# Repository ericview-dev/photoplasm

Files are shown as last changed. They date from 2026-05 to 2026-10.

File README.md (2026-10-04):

# Photoplasm

**Optogenetic bacteriography exposure unit — HTGAA 2026 Final Project**

*Eric Schneider · Makerspace Charlotte · BioArt Studio*

---

## What It Is

Photoplasm is a Raspberry Pi 5-based optogenetic exposure unit designed for bacteriographic imaging — using spatially-patterned 470 nm light to control gene expression in engineered bacteria. A 128×64 OLED acts as a programmable digital photomask, projecting custom grayscale patterns onto a bacterial culture plate through a 470 nm LED ring. An AS7341 spectral sensor measures delivered irradiance at the substrate plane in real time.

The result is a benchtop instrument capable of exposing a bacterial plate to a calibrated, spatially-defined light pattern — the optical equivalent of an enlarger in photographic darkroom practice, but for living cells.

---

## Hardware

| Component | Role |
|---|---|
| Raspberry Pi 5 | Host compute, GPIO, SPI, I²C, PWM |
| Waveshare SSD1309 128×64 OLED (SPI) | Digital photomask — spatial light modulator |
| 9× 470 nm LED ring | Primary illumination source |
| IRLZ44N MOSFET | PWM gate driver for LED ring (GPIO18) |
| Godiyes AS7341 spectral sensor (I²C) | 10-channel irradiance measurement at substrate |
| PTC heater + DS18B20 (1-Wire) | 37°C incubation thermal control |
| Raspberry Pi Camera Module | Sample imaging and machine vision (planned) |

Pin assignments: [`Docs/appendix_C_pinout_NS-03_v8.md`](Docs/appendix_C_pinout_NS-03_v8.md)

---

## Scripts

| Script | Purpose |
|---|---|
| [`Software/photoplasm_densitometer.py`](Software/photoplasm_densitometer.py) | 16-step Bayer dither transmission densitometer — characterises OLED optical neutrality at 470 nm |
| [`Software/photoplasm_cal01.py`](Software/photoplasm_cal01.py) | 16-step sensitometric calibration sweep using cumulative pie-wedge masks (Stouffer step wedge equivalent) |
| [`Software/photoplasm_cal02.py`](Software/photoplasm_cal02.py) | Three-state irradiance calibration (display off / display on / all-white) |

### Quick start — densitometer

```bash
# Install dependencies
sudo apt install python3-lgpio python3-spidev python3-smbus2 python3-pil
sudo pip3 install adafruit-circuitpython-as7341 --break-system-packages

# Run (requires hardware)
sudo python3 Software/photoplasm_densitometer.py

# Dry run — no hardware required
python3 Software/photoplasm_densitometer.py --dry-run

# Options
sudo python3 Software/photoplasm_densitometer.py --gain 128X --settle 2.0 --pwm 80
```

Output: timestamped CSV in `cal_logs/` with per-step spectral channel readings and regression summary printed to stdout.

---

## Documentation

Full build and operation guide in [`Docs/`](Docs/):

| # | Chapter | Status |
|---|---|---|
| 1 | [SSH Setup & VS Code Remote Development](Docs/photoplasm_ch01_ssh.md) | published |
| 2 | [GitHub & Version Control](Docs/photoplasm_ch02_github.md) | published |
| 3 | [Wavelength Sensor — AS7341](Docs/photoplasm_ch03_wavelength_sensor.md) | draft |
| 4 | [LED Ring · 470nm PWM Control](Docs/photoplasm_ch04_led_ring.md) | published |
| 5 | [OLED Digital Image Mask](Docs/photoplasm_ch05_oled_mask.md) | draft |
| 6 | [Incubation Heater Perfboard](Docs/photoplasm_ch06_heater_perfboard.md) | published |
| 7 | [System Integration](Docs/photoplasm_ch07_system_integration.md) | draft |
| 8 | [GUI / Flask Web Interface](Docs/photoplasm_ch08_gui_flask.md) | draft |
| 9 | [SpacePlacer — Perfboard Layout Tool](Docs/photoplasm_ch09_spaceplacer.md) | draft |
| 10 | [Camera Module](Docs/photoplasm_ch10_camera_module.md) | placeholder |
| A | [Calibration Protocol](Docs/appendix_A_calibration_protocol.md) | draft |
| B | [Feature Specification](Docs/appendix_B_feature_specification.md) | working draft |
| C | [Pinout — NS-03 v8](Docs/appendix_C_pinout_NS-03_v8.md) | working draft |

---

## Project Status

Active development on the `dev` branch. Hardware subsystems operational: LED ring, OLED mask, AS7341 sensor, incubation heater. Calibration scripts validated. Flask GUI and camera module in scope.

---

## License

Photoplasm follows a Pioreactor-style open-source model: different parts of the project
carry the license that suits what each part is.

| | | |
|---|---|---|
| `Software/` | **MIT** | permissive reuse, attribution required |
| `Docs/` · `Guide/` | **CC BY-SA 4.0** | share and adapt, including commercially, under the same license |
| `3D/` | **CERN-OHL-S-2.0** | strongly reciprocal hardware licence |

Source code is MIT wherever it sits — placement does not change a file's license, its
nature does. The Photoplasm name, branding, unpublished know-how and separately protected
inventions are reserved and fall outside all three.

Full terms, including third-party materials: [`LICENSE`](LICENSE)

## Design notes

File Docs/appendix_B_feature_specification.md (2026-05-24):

Photoplasm Quick Start Guide  ·  Appendix B: Feature Specification **Photoplasm**

**Appendix B: Feature Specification**

**Version: **v0.18 (working draft)

**Status: **Working functional specification — locks at release milestone **Date: **2026-05-17 **Repository: **github.com/ericview-dev/photoplasm **Author: **Eric Schneider

# About This Document

This appendix is the functional specification for Photoplasm, the Raspberry Pi-based optogenetic exposure unit at the heart of the BioLight project. It catalogs every feature of the device — hardware subsystems, software components, mechanical assemblies, and platform infrastructure — and tracks each feature's design intent, implementation status, and supporting build assets.

The specification is organized as a registry rather than a narrative. Each feature has a permanent identifier (such as LED-01 or CAM-01.2), a category grouping, and a row in the registry table. Detailed specifications for each feature follow the registry in the appendix body. The registry serves as the index; the body provides the depth.

## Working Document, Locked at Release

This is a working functional specification. It evolves as features are designed, scoped, built, and tested. Entries are added, statuses change, sub-features are decomposed, and upgrade paths emerge throughout development. Internal revision history is tracked at the end of this appendix; it captures the document's own evolution and is intended for working reference, not publication.

When Photoplasm reaches a release milestone, the specification is locked: statuses are reconciled, the working revision history is archived, and a final published version is produced. Until then, the specification is a living document, and the registry reflects the current state of the project rather than any single committed plan.

# Legend

## Category Codes

| **Code** | **Category** | **Scope** |
| --- | --- | --- |
| **SYS** | System & Lifecycle | Boot, shutdown, services, power management, platform-level concerns |
| **GUI** | Operator Interface | Flask web UI, kiosk panel, CLI, all user-facing controls |
| **LED** | Light Generation (EBOOT-based) | Current prototype: 9× 470 nm through-hole LEDs |
| **CRE** | Light Generation (Cree XP-E2) | Upgrade lightring: high-output star LEDs with heatsink, diffuser, fan |
| **MSK** | Image Mask | Variable-density image layer between light and sample |
| **WAV** | Spectral Measurement | Wavelength-based sensing of the light source; calibration, characteristic curves |
| **HTR** | Thermal Subsystem | Heater element, MOSFET driver, temperature sensing, control loop |
| **OPT** | Optical Isolation | Dark chamber, frustum, baffles, sample stage, passive optics |
| **CAM** | Imaging & Machine Vision | Camera-based observation of the sample; image acquisition, analysis pipelines |

## Status Lifecycle

| **Status** | **Meaning** |
| --- | --- |
| **🔵 Proposed** | Identified, rationale captured, not yet scoped |
| **🟡 Scoped** | Implementation path defined, parts listed, awaiting build |
| **🟢 In Progress** | Active development; hardware wiring, code, or both underway |
| **🧪 Tested** | Built and bench-verified; awaiting integration into chapter spec |
| **✅ Complete** | Fully specified, built, tested, operational |
| **🗄️ Deferred** | Was active; now paused, superseded, or migrated to another category |
| **⛔ Rejected** | Considered and declined; rationale preserved |

## Upgrade Path Notation

Succession: → FEATURE-ID (superseded) or → FEATURE-ID.x (gains a sub-variant).

Gating: Gates FEATURE-ID — milestone dependency. A feature in the gating role typically defines a pass/fail criterion in its Brief Description.

# Feature Specification Registry

## 1. SYS — System & Lifecycle

| **ID** | **Title** | **Brief Description** | **Ch.** | **Status** | **Asset** | **Upgrade** |
| --- | --- | --- | --- | --- | --- | --- |
| **SYS-01** | Shutdown Button | GPIO21 momentary pull-up, graceful shutdown trigger | Ch. 7 | ✅ Complete | ✅ sys_01_shutdown.py | → SYS-03.2 |
| **SYS-02** | System Endpoints | /api/system/{shutdown,reboot,status} + signal handlers | Ch. 8 | 🟡 Scoped | 📝 sys_02_endpoints.py | → SYS-03 |
| **SYS-03** | Power Module | On/off/reboot module: hard switch, soft buttons, wake control | Ch. 8 | 🔵 Proposed | 📝 sys_03_power.py | — |
| **SYS-03.1** | Hard Power Switch | SPST rocker, 5V interrupt | Ch. 8 | 🔵 Proposed | ⬜ N/A | — |
| **SYS-03.2** | Soft Shutdown Button | Momentary, GPIO-triggered graceful shutdown (replaces SYS-01) | Ch. 8 | 🔵 Proposed | 📝 sys_03_2_soft_shutdown.py | — |
| **SYS-03.3** | Wake Button | Momentary on Pi 5 PWR_BTN header for wake-from-shutdown | Ch. 8 | 🔵 Proposed | ⬜ N/A | — |
| **SYS-03.4** | Reboot Control | Separate button or long-press gesture for reboot vs shutdown | Ch. 8 | 🔵 Proposed | 📝 sys_03_4_reboot.py | — |
| **SYS-04** | Battery Backup / UPS | Li-ion UPS HAT for graceful shutdown on power loss | Ch. 8 | 🔵 Proposed | 📝 sys_04_ups.py | — |
| **SYS-05** | Status LED Indicators | Front-panel LED stack | Ch. 8 | 🔵 Proposed | 📝 sys_05_status_leds.py | — |
| **SYS-05.1** | Pi Powered LED | Tied to 3V3 rail, lights when Pi has power | Ch. 8 | 🔵 Proposed | ⬜ N/A | — |
| **SYS-05.2** | System Ready LED | GPIO-driven, lights when Flask /health returns 200 | Ch. 8 | 🔵 Proposed | 📝 sys_05_2_ready_led.py | — |
| **SYS-05.3** | Shutdown In Progress LED | Blinks during graceful shutdown sequence | Ch. 8 | 🔵 Proposed | 📝 sys_05_3_shutdown_led.py | — |
| **SYS-06** | Battery-Backed RTC | Pi 5 onboard RTC with CR2032 cell for timestamp persistence | Ch. 8 | 🔵 Proposed | ⬜ N/A | — |
| **SYS-07** | Audible Status Cues | Piezo buzzer for shutdown, exposure complete, error states | Ch. 8 | 🔵 Proposed | 📝 sys_07_buzzer.py | — |
| **SYS-08** | Logging Infrastructure | Timestamped CSV writer shared across calibration + Flask | App. A / Ch. 7 | ✅ Complete | 🚧 sys_08_logger.py | — |
| **SYS-09** | lgpio Handle Pool | Shared GPIO claim/release management | Ch. 7 | ✅ Complete | 🚧 sys_09_gpio_pool.py | — |
| **SYS-10** | systemd Service Definition | Flask service unit for boot-time start | Ch. 8 | 🟡 Scoped | 📝 sys_10_photoplasm.service | Gates GUI-01, GUI-02 |
| **SYS-11** | Headless Pi 5 Configuration | OS install, hostname eyepi, user ericview, SSH, GPIO permissions | Ch. 7 | ✅ Complete | ⬜ N/A | — |
| **SYS-12** | Repo Sync Workflow | Three-way Mac ↔ GitHub ↔ Pi sync with HTTPS auth | Ch. 7 | ✅ Complete | ⬜ N/A | — |

## 2. GUI — Operator Interface

| **ID** | **Title** | **Brief Description** | **Ch.** | **Status** | **Asset** | **Upgrade** |
| --- | --- | --- | --- | --- | --- | --- |
| **GUI-01** | Flask UI — Mode 1 (Browser) | Browser-based control at http://eyepi.local:5000, systemd-managed | Ch. 8 | 🟡 Scoped | 📝 gui_01_browser.py | — |
| **GUI-02** | Flask UI — Mode 2 (Kiosk) | Chromium kiosk on Micro HDMI touchscreen, shares Mode 1 codebase | Ch. 8 | 🟡 Scoped | 📝 gui_02_kiosk.py | — |
| **GUI-02.1** | Chromium Launch Script | Kiosk-mode browser invocation with localhost target | Ch. 8 | 🟡 Scoped | 📝 gui_02_1_chromium_launch.sh | — |
| **GUI-02.2** | Touchscreen Hardware | 5-7" capacitive HDMI/DSI panel (specific model TBD) | Ch. 8 | 🔵 Proposed | ⬜ N/A | — |
| **GUI-03** | Click CLI Layer | flask photoplasm <subcommand> — unified CLI/web control path | Ch. 8 | 🟡 Scoped | 📝 gui_03_cli.py | — |
| **GUI-04** | Exposure Scheduling | Scheduled runs with duration, intensity, mask, incubation params | Ch. 8 | 🟡 Scoped | 📝 gui_04_scheduler.py | — |
| **GUI-05** | Mask Upload & Library | PNG/SVG upload to mask buffer with re-usable mask library | Ch. 8 | 🟡 Scoped | 📝 gui_05_mask_library.py | — |
| **GUI-06** | Live Sensor Dashboard | Real-time AS7341 + DS18B20 stream via SSE/WebSocket | Ch. 8 | 🟡 Scoped | 📝 gui_06_dashboard.py | — |
| **GUI-07** | Session Logging UI | Per-session timestamped CSV, downloadable from UI | Ch. 8 | 🟡 Scoped | 📝 gui_07_session_log.py | — |
| **GUI-08** | Touch-First UI Conventions | ≥64 px tap targets, bold typography, single stylesheet | Ch. 8 | 🟡 Scoped | 📝 gui_08_styles.css | — |
| **GUI-09** | Safelight-Aware Color Palette | Cool-tone primary chrome, red reserved for safelight-invisible states | Ch. 8 | 🟡 Scoped | 📝 gui_09_colors.css | — |
| **GUI-10** | Error State Handling | UI surfaces for hardware fault, sensor disconnect, mid-exposure failures | Ch. 8 | 🟡 Scoped | 📝 gui_10_errors.py | — |
| **GUI-11** | Multi-Client Concurrency | SSE/WebSocket fan-out for simultaneous browser + kiosk sessions | Ch. 8 | 🟡 Scoped | 📝 gui_11_realtime.py | — |

## 3. LED — Light Generation (EBOOT-based Lightring)

| **ID** | **Title** | **Brief Description** | **Ch.** | **Status** | **Asset** | **Upgrade** |
| --- | --- | --- | --- | --- | --- | --- |
| **LED-01** | LED Subsystem (Parent, EBOOT-based) | Variable-intensity 470 nm lightring; current prototype implementation | Ch. 4 | ✅ Complete | ✅ led_01_driver.py | → CRE-01 |
| **LED-01.1** | Breadboard/Protoboard Breakout | 9× 470 nm EBOOT LEDs, 3 strings of 3 series, 3×120Ω, 30-row protoboard | Ch. 4 | ✅ Complete | ✅ Present | → CRE-01 |
| **LED-01.2** | LED Matrix Board (alpha_01) | 120×120×2mm PETG, 9×9 diagonal RGB interleave, designed not built | Ch. 4 | 🟡 Scoped | 🚧 led_3D_01_2_matrix | → CRE-02 |
| **LED-01.3** | IRLZ44N PWM Gate Circuit | IRLZ44N at I15/I16/I17, 10kΩ G17-F20→GND, 3.3V gate at H17 | Ch. 4 | ✅ Complete | ✅ Present | — |
| **LED-03** | PWM Frequency Selection | LED PWM frequency (kHz) vs heater PWM (1-10 Hz) calibration | Ch. 4/7 | ✅ Complete | ✅ in led_01_driver.py | — |
| **LED-04** | Irradiance Measurement (EBOOT) | ~2.0 µW/cm² at 445nm; ~50× below 100 µW/cm² uncalibrated threshold² for blue-light optogenetic activation. Insufficient for eLightOn; drives CRE upgrade | Ch. 3 | ✅ Complete | ⬜ N/A | — |

## 4. CRE — Light Generation (Cree XP-E2 Lightring) — Priority 2 Upgrade

| **ID** | **Title** | **Brief Description** | **Ch.** | **Status** | **Asset** | **Upgrade** |
| --- | --- | --- | --- | --- | --- | --- |
| **CRE-01** | Cree Lightring Subsystem (Parent) | High-output Cree XP-E2 3-up star LED lightring; supersedes LED-01 at full integration | Ch. 4 | 🟡 Scoped (P2) | 📝 cre_01_driver.py | — |
| **CRE-01.1** | XP-E2 3-Up Star LEDs | 3× Cree XP-E2 3-up star modules (9 emitters total at 470 nm) — ordered | Ch. 4 | 🟡 Scoped (P2) | ⬜ N/A | — |
| **CRE-01.2** | 6.8Ω 2W Current-Limiting Resistors | Drive current resistors at 12V rail for rated XP-E2 forward current | Ch. 4 | 🟡 Scoped (P2) | ⬜ N/A | — |
| **CRE-01.3** | Passive Heatsink | Thermal management for star LED substrate, continuous-duty sized | Ch. 4 | 🔵 Proposed (P2) | 📝 cre_3D_01_3_heatsink | — |
| **CRE-01.4** | Active Cooling Fan | Forced airflow over heatsink for sustained high-drive operation | Ch. 4 | 🔵 Proposed (P2) | 📝 cre_01_4_fan.py | — |
| **CRE-01.5** | Light Diffuser | Optical diffuser to spread point-source emission for uniform exposure plane | Ch. 4/6 | 🔵 Proposed (P2) | 📝 cre_3D_01_5_diffuser | — |
| **CRE-02** | CRE Lightring Protoboard Design¹ | New SpacePlacer JSON sidecar; produced by existing SpacePlacer tool, no tool changes required | Ch. 4 | 🔵 Proposed (P2) | 📝 cre_lightring_alpha_01.json | — |
| **CRE-02.1** | CRE Layout JSON Artifact | cre_lightring_alpha_01.json — versioned design file in spaceplacer repo | Ch. 4 | 🔵 Proposed (P2) | 📝 cre_lightring_alpha_01.json | — |
| **CRE-02.2** | Heatsink Mounting Cutouts | Layout features for thermal contact between star LED substrate and heatsink | Ch. 4 | 🔵 Proposed (P2) | 📝 cre_3D_02_2_cutouts | — |
| **CRE-02.3** | Fan Mounting Provisions | Mechanical and electrical layout provisions for active cooling fan | Ch. 4 | 🔵 Proposed (P2) | 📝 cre_3D_02_3_fan_mount | — |
| **CRE-03** | CRE PWM Driver Adaptation | IRLZ44N driver verification at XP-E2 drive current; may require different gate scheme | Ch. 4 | 🔵 Proposed (P2) | 📝 in cre_01_driver.py | Gates CRE-01 |
| **CRE-04** | CRE Irradiance Measurement (Migration Gate) | AS7341 calibration of CRE at 470nm. Pass if ≥100 µW/cm²² (uncalibrated threshold). Fail if <100 µW/cm² (returns to engineering revision) | App. A | 🔵 Proposed (P2) | 📝 cre_04_irradiance.py | Gates CRE-06 |
| **CRE-05** | CRE Integration with Frustum Optics | Mounting and alignment of CRE assembly to existing OPT-01 dark chamber | Ch. 6 | 🔵 Proposed (P2) | 📝 cre_3D_05_frustum_adapter | — |
| **CRE-06** | CRE Migration & Cutover Plan | Procedure for swapping LED-01 → CRE-01 in operational unit | Ch. 4/7 | 🔵 Proposed (P2) | ⬜ N/A | — |

## 5. MSK — Image Mask

| **ID** | **Title** | **Brief Description** | **Ch.** | **Status** | **Asset** | **Upgrade** |
| --- | --- | --- | --- | --- | --- | --- |
| **MSK-01** | Image Mask Subsystem (Parent) | Variable-density image layer between LightRing and sample | Ch. 4/7 | ✅ Complete | ✅ msk_01_mask.py | — |
| **MSK-01.1** | OLED Implementation (SSD1309) | SPI transmissive mask — currently active, has 470 nm self-emission limitation | Ch. 4/7 | ✅ Complete | ✅ msk_01_1_oled.py | → MSK-01.2 |
| **MSK-01.2** | LCD Implementation (ILI9341) | Transmissive LCD backlit by LED array; eliminates self-emission | Ch. 4 | 🔵 Proposed | 📝 msk_01_2_lcd.py | — |
| **MSK-01.3** | Mask Mounting Hardware | Physical mount between LED rail and image mask layer | Ch. 6 | ✅ Complete | 🚧 msk_3D_01_3_mount | — |
| **MSK-02** | Bayer Dither Mask Generation | 16-step density gradient mask generation for densitometer sweeps | App. A | ✅ Complete | ✅ in wav_03_densitometer.py | — |

## 6. WAV — Spectral Measurement & Calibration

| **ID** | **Title** | **Brief Description** | **Ch.** | **Status** | **Asset** | **Upgrade** |
| --- | --- | --- | --- | --- | --- | --- |
| **WAV-01** | AS7341 Sensor | 10-channel I²C sensor at 0x39, drives calibration pipeline | Ch. 3 | ✅ Complete | ✅ wav_01_as7341.py | — |
| **WAV-01.1** | F1-F8 Spectral Channel Mapping | 415/445/480/515/555/590/630/680 nm channel definitions | Ch. 3 | ✅ Complete | ✅ in wav_01_as7341.py | — |
| **WAV-02** | Calibration Pipeline (Current) | Three-state irradiance, λex proxy, CSV logging | App. A | ✅ Complete | ✅ wav_02_calibration.py | — |
| **WAV-02.1** | Three-State Irradiance Method | Off / OLED-only / full exposure measurement methodology | App. A | ✅ Complete | ✅ in wav_02_calibration.py | — |
| **WAV-02.2** | λex Excitation Proxy | F2₄₄₅ + F3₄₈₀ summed-channel proxy for 470 nm excitation | App. A | ✅ Complete | ✅ in wav_02_calibration.py | — |
| **WAV-03** | Densitometer / H&D Sweep | 16-step Bayer dither, characteristic curves | App. A | ✅ Complete | ✅ wav_03_densitometer.py | — |
| **WAV-04** | (migrated to CAM-01) | Pi Camera Module — was tracked here under WAV when imaging was treated as a spectral concern; migrated to CAM category v0.14 | — | 🗄️ Deferred | — | → CAM-01 |
| **WAV-05** | Kc Coefficient Integration | Holds the irradiance coefficient (Kc) used to convert AS7341 raw counts to absolute µW/cm². Value derived externally through BioLight calibration protocol; Photoplasm consumes as configuration parameter | App. A | 🔵 Proposed | 📝 wav_05_kc_integration.py | — |
| **WAV-06** | Luminosity Reference (Clear Channel) | AS7341 clear channel for total flux measurement | App. A | ✅ Complete | ✅ in wav_02_calibration.py | — |

## 7. HTR — Thermal Subsystem

| **ID** | **Title** | **Brief Description** | **Ch.** | **Status** | **Asset** | **Upgrade** |
| --- | --- | --- | --- | --- | --- | --- |
| **HTR-01** | DS18B20 Temperature Sensor | 1-Wire sensor on GPIO4 (Pin 7), feeds heater control loop | Ch. 4/7 | ✅ Complete | ✅ htr_01_ds18b20.py | — |
| **HTR-01.1** | DS18B20 JST Wiring | T7=Data(orange/yellow), T8=GND(gray/black), T9=VDD(blue/red) | Ch. 4 | ✅ Complete | ⬜ N/A | — |
| **HTR-02** | PTC Element & Driver (Board B) | PTC via IRLZ44N on GPIO13/PWM1, closed loop with DS18B20 feedback | Ch. 4/7 | 🟡 Scoped | 📝 htr_02_controller.py | — |
| **HTR-02.1** | PTC Heating Element | Self-regulating positive-temperature-coefficient element | Ch. 4 | 🟡 Scoped | ⬜ N/A | — |
| **HTR-02.2** | IRLZ44N MOSFET Driver | Gate-driven from GPIO13/PWM1, switches 12V to PTC | Ch. 4 | 🟡 Scoped | ⬜ N/A | — |
| **HTR-02.3** | Heater PTC JST Connector | T4=PTC+, T5=PTC- | Ch. 4 | 🟡 Scoped | ⬜ N/A | — |
| **HTR-02.4** | Heater Board Layout (SpacePlacer) | Perfboard layout designed in github.com/ericview-dev/spaceplacer | Ch. 4 | 🟡 Scoped | 🚧 Board B JSON (spaceplacer) | — |
| **HTR-03** | PWM Bench Test Sequence | Independent verification of GPIO13/PWM1 before integration | Ch. 7 | 🟡 Scoped | 📝 htr_03_pwm_test.py | Gates HTR-02 |
| **HTR-04** | PID Control Loop | Temperature setpoint hold for 37 °C incubation | Ch. 8 | 🔵 Proposed | 📝 htr_04_pid.py | — |
| **HTR-05** | Heater Board Chamber | Physical enclosure subsection for Board B | Ch. 6 | 🔵 Proposed | 📝 htr_3D_05_chamber | — |

## 8. OPT — Optical Isolation

| **ID** | **Title** | **Brief Description** | **Ch.** | **Status** | **Asset** | **Upgrade** |
| --- | --- | --- | --- | --- | --- | --- |
| **OPT-01** | Dark Chamber — Frustum & Spacer Rings | Fixed cone (256mm × 51mm top × 152mm base) + stackable PETG spacers | Ch. 6 | ✅ Complete | ⬜ N/A | — |
| **OPT-01.1** | Frustum Cone | 256 mm height, 51 mm top ID, 152 mm base OD, PETG | Ch. 6 | ✅ Complete | 🚧 opt_3D_01_1_frustum | — |
| **OPT-01.2** | Spacer Ring (50 mm) | Stackable spacer for 6"-12" throw distance adjustment | Ch. 6 | ✅ Complete | 🚧 opt_3D_01_2_spacer | — |
| **OPT-02** | Modular Stacking Enclosure | PETG enclosure housing Pi, LED, mask, AS7341 | Ch. 6 | 🟢 In Progress | 🚧 opt_3D_02_enclosure | — |
| **OPT-03** | Sample Stage | Plate-holding stage at base of frustum (84 mm agar plate target) | Ch. 6 | ✅ Complete | 🚧 opt_3D_03_sample_stage | — |
| **OPT-04** | Light-Tight Sealing | Gaskets and overlap between stacked modules to prevent ambient leak | Ch. 6 | 🟡 Scoped | 📝 opt_3D_04_seals | — |

## 9. CAM — Imaging & Machine Vision

| **ID** | **Title** | **Brief Description** | **Ch.** | **Status** | **Asset** | **Upgrade** |
| --- | --- | --- | --- | --- | --- | --- |
| **CAM-01** | Pi Camera Module (Machine Vision) | RPi Camera Module for post-exposure sample imaging and fluorescence quantification | Ch. 10 | 🔵 Proposed | 📝 cam_01_capture.py | — |
| **CAM-01.1** | Camera Mount (Oblique or Under-Plate) | Physical mounting for fluorescence imaging at base of frustum | Ch. 6 | 🔵 Proposed | 📝 cam_3D_01_1_mount | — |
| **CAM-01.2** | Fluorescence Analytics Pipeline | Python image-analysis for sfGFP quantification | Ch. 10 | 🔵 Proposed | 📝 cam_01_2_fluorescence.py | — |

# Registry Footnotes

*Footnote markers are spaced superscript numerals following the relevant text (e.g., **"**µW/cm² ²**"**). The unspaced **"**²**"** in I²C elsewhere in the registry is the standard typographic rendering of the Inter-Integrated Circuit protocol name and is not a footnote reference.*

### ¹ CRE-02 SpacePlacer Note

CRE-02 is a JSON design artifact produced by SpacePlacer's existing perfboard substrate model. No SpacePlacer tool changes are required for CRE-02 to proceed. A separate concept — a proto-breadboard framework extending SpacePlacer's grid-and-component model to handle additional substrate types — has been discussed as a potential aid to future board designs, but is a SpacePlacer feature, not a Photoplasm feature. It is tracked at priority scope (P2-spaceplacer) in the SpacePlacer roadmap and does not gate CRE-02.

### ² Irradiance Calculation and Calibration

Irradiance values in this specification (LED-04, CRE-04, and any other µW/cm² references) are derived from AS7341 spectral channel readings via the calibration methodology documented in Appendix A: Calibration Protocol. The relevant features in this registry are:

WAV-02 — Calibration Pipeline (photoplasm_cal02.py)

WAV-02.1 — Three-state irradiance method (off / mask-only / full exposure)

WAV-02.2 — λex excitation proxy formula (F2₄₄₅ + F3₄₈₀ summed-channel proxy for 470 nm)

WAV-05 — Kc Coefficient Integration — applies the externally-derived Kc to convert AS7341 counts to absolute µW/cm² **Two-path measurement. Absolute irradiance can be obtained two ways: (1) direct measurement with an external calibrated photospectrometer at the plate plane, which is metrologically traceable but slow and requires wet-lab access; or (2) derived measurement through the onboard AS7341 multiplied by the Kc coefficient, which is fast and in-situ but only as accurate as the most recent Kc calibration.**

**Kc calibration is a refinement, not a prerequisite. Photoplasm delivers controlled, repeatable exposures using the onboard AS7341 in its uncalibrated state. Until a Kc value is received from BioLight****'****s calibration protocol, the 100 µW/cm² target in LED-04 and CRE-04 should be read as an uncalibrated minimum threshold rather than a metrologically traceable absolute value. The CRE-04 pass/fail migration gate can be evaluated against uncalibrated readings; metrological re-verification is a separate quality step.**

# Cross-Project References

## SpacePlacer (perfboard/PCB design tool)

| **Photoplasm Feature** | **SpacePlacer Dependency** | **Status** |
| --- | --- | --- |
| CRE-02 (CRE Lightring Protoboard Design) | Uses existing SpacePlacer perfboard model; no SpacePlacer changes required | No dependency |
| (potential future) — multi-substrate board designs | Proto-breadboard framework concept | (P2-spaceplacer) |
| HTR-02.4 (Heater Board Layout) | Uses existing SpacePlacer v0.1 perfboard model | No dependency |

## BioLight (wetware project)

**Target optogenetic system: eLightOn (RsLOV-LexA408 / pColE408, 470 nm activation, sfGFP reporter). Photoplasm****'****s light-delivery specifications — wavelength selection, irradiance targets, exposure scheduling — are calibrated for eLightOn as the sole optogenetic system across all BioLight aims.**

| **Photoplasm Feature** | **BioLight Relationship** |
| --- | --- |
| MSK-01.1 (OLED mask) | Provides image-mask substrate for BioLight Aim 1A optogenetic exposure |
| CAM-01 (Pi Camera Module) | Enables sfGFP fluorescence quantification per BioLight Aim 1A/1B protocols |
| HTR-02 (Heater) | Provides 37°C incubation for BioLight wet-lab protocols |
| LED-04 / CRE-04 (Irradiance milestones) | Verify light output meets blue-light optogenetic activation thresholds; CRE-04 gates the LED-01 → CRE-01 migration |
| WAV-05 (Kc Coefficient Integration) | BioLight owns the Kc calibration protocol. The cross-instrument calibration (Photoplasm AS7341 vs. external wet-lab photospectrometer) is wet-lab methodology — sample geometry, replicate counts, statistical derivation, validation — that lives in BioLight's experimental documentation. Photoplasm consumes the resulting Kc value as a configuration parameter. (P2-biolight scope; depends on wet-lab photospectrometer access at Genspace or equivalent.) |

*Important boundary: Kc calibration is not a prerequisite for the Photoplasm device build. The device delivers controlled, repeatable exposures using the onboard AS7341 in its uncalibrated state. Kc calibration adds metrological traceability — the ability to report irradiance in standardized µW/cm² units — but does not affect the device**'**s exposure capability, repeatability, or scientific utility for relative measurements.*

# Registry Summary

| **Category** | **Total** | **✅ Complete** | **🟢 In Progress** | **🟡 Scoped** | **🔵 Proposed** | **🗄️ Deferred** |
| --- | --- | --- | --- | --- | --- | --- |
| SYS | 19 | 5 | 0 | 2 | 12 | 0 |
| GUI | 13 | 0 | 0 | 12 | 1 | 0 |
| LED | 6 | 5 | 0 | 1 | 0 | 0 |
| CRE (P2) | 14 | 0 | 0 | 3 | 11 | 0 |
| MSK | 5 | 4 | 0 | 0 | 1 | 0 |
| WAV | 9 | 6 | 0 | 0 | 2 | 1 |
| HTR | 10 | 2 | 0 | 6 | 2 | 0 |
| OPT | 6 | 4 | 1 | 1 | 0 | 0 |
| CAM | 3 | 0 | 0 | 0 | 3 | 0 |
| **Total** | **85** | **26** | **1** | **25** | **32** | **1** |

# Per-Feature Specifications

*Detailed specifications for each feature follow. Spec sections are drafted in priority order: ✅ Complete entries back-documented first, then 🟢/🟡 entries as the primary active-development target, with 🔵 Proposed entries deferred until scoped.*

*(85 feature specification stubs awaiting drafts — to be developed in subsequent sessions.)*

# Universal Design & UI Validation

*Closing section addressing accessibility considerations, Universal Design principles, and empirical interface testing methodology under wet-lab conditions. To be developed once the functional specification body is sufficiently mature to support meaningful validation criteria.*

---

*Photoplasm · HTGAA 2026 · Genspace Node · Eric Schneider · Makerspace Charlotte*

*Repository: github.com/ericview-dev/photoplasm · branch: dev*

> v0.18  ·  2026-05-17  ·  working draft

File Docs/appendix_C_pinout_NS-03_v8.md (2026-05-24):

Photoplasm Quick Start Guide  ·  Appendix C: Pi 5 Pinout — NS-03 v8

# Appendix C: Pi 5 Pinout — NS-03 v8

*Eric Schneider · Makerspace Charlotte · HTGAA 2026*

Version 8  ·  2026-05-17  ·  github.com/ericview-dev/photoplasm

---

## **Document Metadata**

| **Project** | Photoplasm |
| --- | --- |
| **Subsystem** | Hardware / Pin Assignment |
| **Version** | v8 |
| **Status** | PWM channels separated; heater PWM1 paper-assigned (not yet bench-tested) |
| **Date** | 2026-05-17 |
| **Supersedes** | NS-03 v7 (Apr 2026) |
| **Repository** | github.com/ericview-dev/photoplasm |
| **Author** | Eric Schneider |

Canonical hardware reference for the Photoplasm optogenetics exposure unit (Raspberry Pi 5, hostname eyepi, user ericview). This document is the authoritative pin assignment source; any code, schematic, or chapter that references pin numbers must reconcile to this file.

## **Test Status Legend**

| **Symbol** | **Meaning** |
| --- | --- |
| **✅ ACTIVE** | Wired, code-verified, bench-confirmed |
| **⚠️ ASSIGNED** | Pin reserved in software/docs; NOT yet bench-tested |
| 🔒 RESERVED | Held for future use; no current consumer |
| — | Power, ground, or no-connect |

## **Group A — Hardware PWM**

Pi 5 exposes two independent hardware PWM channels. Each channel can route to one of two GPIOs; the channels are independent of each other and require no mutex or time-multiplexing in software.

| **Channel** | **GPIO** | **Pin** | **Consumer** | **Driver** | **Status** |
| --- | --- | --- | --- | --- | --- |
| **PWM0** | GPIO18 | **12** | LED ring (470 nm, 9× via IRLZ44N) | lgpio.tx_pwm | **✅ ACTIVE** |
| **PWM1** | GPIO13 | **33** | Heater MOSFET (PTC element, Board B) | lgpio.tx_pwm | **⚠️ NOT YET TESTED** |

**PWM0 alternate (unused): **GPIO12 / Pin 32 — conflicts with GPIO18 if enabled.

**PWM1 alternate (blocked): **GPIO19 / Pin 35 — occupied by OLED SPI block.

### **Heater PWM1 bench-test gate**

Before promoting Pin 33 / GPIO13 to ✅ ACTIVE, complete:

**1. **lgpio claim GPIO13 as output, tx_pwm at 10 % duty, low frequency (1–10 Hz appropriate for thermal mass).

**2. **Confirm PWM waveform on MOSFET gate via scope or indirect LED-on-gate visual check.

**3. **Run LED PWM0 (GPIO18) and heater PWM1 (GPIO13) simultaneously; confirm no cross-channel interference.

**4. **Confirm DS18B20 reads valid temperature while heater duty cycles.

**5. **Document chosen PWM frequency in code comments and update this file to v9.

*Until those five steps are complete, Ch. 8 Flask UI must treat the heater endpoint as simulation-only (no actual GPIO13 output) or behind an explicit --enable-heater-pwm flag.*

## **Group B — Communication Buses**

| **Bus** | **Pins** | **GPIOs** | **Consumer** | **Address / CS** | **Status** |
| --- | --- | --- | --- | --- | --- |
| I²C | 3, 5 | GPIO2 (SDA), GPIO3 (SCL) | AS7341 spectral sensor | 0x39 | ✅ ACTIVE |
| SPI | 19, 21, 23, 24 | GPIO10 (MOSI), GPIO9 (MISO), GPIO11 (SCLK), GPIO8 (CE0) | OLED SSD1309 image mask | CE0 | ✅ ACTIVE |
| OLED control | 13, 17, 22 | GPIO27 (DC), GPIO11/shared, GPIO25 (RST) | OLED SSD1309 control lines | — | ✅ ACTIVE |
| 1-Wire | 7 | GPIO4 | DS18B20 temperature sensor | — | ✅ ACTIVE |

**Note on Pin 13 vs GPIO13 confusion: **Pin 13 is GPIO27 (in the OLED block). GPIO13 is Pin 33 (the new heater PWM1). Always use the Pin/GPIO pair when discussing assignments.

## **Group C — Discrete GPIO**

| **GPIO** | **Pin** | **Consumer** | **Mode** | **Status** |
| --- | --- | --- | --- | --- |
| GPIO21 | 40 | Shutdown button | Input, momentary, pull-up | ✅ ACTIVE |

## **Group D — Power ****&**** Ground**

| **Rail** | **Pin** | **Destination** | **Notes** |
| --- | --- | --- | --- |
| 3V3 | 1 | AS7341 only | Dedicated to sensor — keeps noise off LED rail |
| 3V3 | 17 | LED board right rail (+) | Logic-level supply; OLED + Heater Board tap I10 / H8 off this rail |
| GND | 6 | LED board right rail (−) | Common ground reference |

*12 V rail for LED drive and heater PTC is external (not from Pi headers). GPIO PWM controls IRLZ44N MOSFETs that switch the 12 V rail.*

## **Group E — DS18B20 JST Pin Mapping (Sensor Side)**

Wire colors follow the OEM cable convention (where applicable, vendor-dependent).

| **JST Pin** | **Function** | **Wire Color (OEM)** | **Pi Connection** |
| --- | --- | --- | --- |
| **J3** | Data | Orange / Yellow | Pin 7 / GPIO4 (1-Wire) |
| **J4** | GND | Gray / Black | Pi GND |
| **J5** | VDD | Blue / Red | Pi 3V3 |

## **Group F — Heater PTC Element JST Mapping (Board B)**

| **JST Pin** | **Function** | **Connection** |
| --- | --- | --- |
| **J1** | PTC+ | 12 V rail (MOSFET drain side) |
| **J2** | PTC− | GND via IRLZ44N source |

Heater MOSFET gate is driven by GPIO13 / Pin 33 (PWM1) via Heater Board's gate resistor network. **Not yet bench-verified — see Group A test gate.**

## **Pinout Index (Pin Number → Function)**

| **Pin** | **GPIO** | **Function** | **Status** |
| --- | --- | --- | --- |
| 1 | — | 3V3 → AS7341 | ✅ |
| 3 | GPIO2 | I²C SDA → AS7341 | ✅ |
| 5 | GPIO3 | I²C SCL → AS7341 | ✅ |
| 6 | — | GND → LED rail (−) | ✅ |
| 7 | GPIO4 | 1-Wire → DS18B20 Data | ✅ |
| 9 | — | SPI block (OLED) | ✅ |
| **12** | **GPIO18** | **PWM0 → LED MOSFET gate** | **✅** |
| 13 | GPIO27 | SPI block (OLED control) | ✅ |
| 14 | — | GND (AS7341 / I²C) | ✅ |
| 17 | — | 3V3 → LED rail (+) | ✅ |
| 19 | GPIO10 | SPI MOSI (OLED) | ✅ |
| 21 | GPIO9 | SPI MISO (OLED) | ✅ |
| 22 | GPIO25 | OLED RST | ✅ |
| 23 | GPIO11 | SPI SCLK (OLED) | ✅ |
| 24 | GPIO8 | SPI CE0 (OLED) | ✅ |
| **33** | **GPIO13** | **PWM1 → Heater MOSFET gate** | **⚠️ NOT YET TESTED** |
| 40 | GPIO21 | Shutdown button | ✅ |

*All other pins: unused / no-connect. Available for future expansion (camera module, additional sensors, Aim 2 transmissive LCD upgrade).*

## **Change Log**

### **v8 — 2026-05-17**

• Promoted heater PWM: Pin 33 / GPIO13 moved from 🔒 RESERVED to ⚠️ ASSIGNED (PWM1 channel).

• Reclassified DS18B20: Pin 7 / GPIO4 explicitly listed as ✅ ACTIVE 1-Wire (was implicit under "reserved temp/bed" in v7).

• Resolved PWM contention: LED and heater now on independent hardware PWM channels (PWM0 and PWM1); no time-multiplexing required.

• Added test-gate criteria for promoting GPIO13 from ⚠️ to ✅.

• Added pin-number → GPIO-number disambiguation note (Pin 13 ≠ GPIO13).

### **v7 — Apr 2026**

• LED PWM0 verified at GPIO18.

• OLED SPI block locked.

• AS7341 I²C confirmed at 0x39.

• DS18B20 JST color mapping documented.

• Heater pins (7, 33) marked reserved pending Board B design.

## **References**

• Board B (Heater Board) circuit design: SpacePlacer v0.1 export, github.com/ericview-dev/spaceplacer • LED PWM build notes: github.com/ericview-dev/photoplasm, dev branch, photoplasm_cal02.py • HTGAA 2026 final project Section 4 (Protocol Design 2): AS7341 calibration + duty cycle reference • Chapter 7 (System Integration) of the Photoplasm Guide: full hardware stack context • Chapter 8 (Flask UI) of the Photoplasm Guide: consumer of this pin table — to be drafted in dedicated session

---

*Photoplasm · HTGAA 2026 · Genspace Node · Eric Schneider · Makerspace Charlotte*

*Repository: github.com/ericview-dev/photoplasm · branch: dev*

> v8  ·  2026-05-17  ·  working draft

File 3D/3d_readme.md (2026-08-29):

# 3D Printed Parts

Printable mechanical components for the Photoplasm optogenetic exposure unit.

Binary STL exported from Fusion 360. Source CAD is not tracked here.

> ## ⚠ PETG — every part, no exceptions
>
> **Print the entire device in PETG.** Not "PETG where it gets hot" — PETG throughout. Two reasons,
> and the second is the one that is easy to miss.
>
> ### 1. PLA cannot survive the light or heater paths
>
> | | Glass transition | Against |
> |---|---|---|
> | **PLA** | **≈ 55–60 °C** | ⛔ **at or below the operating ceiling** |
> | **PETG** | **≈ 80 °C** | ✅ ~25 °C of margin |
>
> The heater's **KSD9700 opens at 55 °C** — that is the designed fault ceiling, so chamber parts are
> *expected* to reach it. **PLA is at its glass transition at exactly that temperature**: it softens,
> creeps under load, and a snap or friction fit lets go. On the light side the Cree heat sink sheds
> **~3.3 W** continuously into whatever carries it.
>
> Parts in these paths: **01, 06, 09, 10, 11** (heater column) and **04, 05, 13** (light/optical
> path). But see below — do not treat that as a permission list for the others.
>
> ### 2. Mixed filament breaks the interference fits — this is the real argument
>
> This stack holds itself together by **fit**, not fasteners: part 11 snaps inside part 06's bore,
> part 13 grips the light spacer by friction, every ring nests on a register lip, and the spacer
> tolerances run to tenths of a millimetre.
>
> **Different polymers have different thermal expansion and different creep rates.** Print two mating
> parts in different filaments and their interference stops being a constant — it drifts with
> temperature, and the two halves relax at different rates under sustained load. A fit dialled in on
> the bench then changes at 37 °C incubation.
>
> **One filament across the whole device keeps every fit predictable.** That is why the rule is *all
> parts consistently PETG*, including the ones that never get warm.
>
> **Also:** PETG takes the **M2/M3 heat-set inserts** at a 230–250 °C iron, and accepts the optional
> **UV-resin sterilisation coating** on part 01. Both are PETG-specific and neither is a
> print-it-in-anything property.

| ID | Part | File | Feature |
|---|---|---|---|
| 01 | Plate Holder | [`Plate_Holder.stl`](Plate_Holder.stl) | OPT-03 |
| 02 | Lower Stage Sensor Mount | [`lower_stage_sensor.stl`](lower_stage_sensor.stl) | Ch. 3 |
| 03 | LCD Carrier | [`LCD_Carrier_1.1_CF.stl`](LCD_Carrier_1.1_CF.stl) | MSK-01.3 |
| 04 | Cone | [`Cone.stl`](Cone.stl) | OPT-01.1 |
| 05 | Cone Spacer, 1 in | [`Cone_Spacer_1in.stl`](Cone_Spacer_1in.stl) | OPT-01.2 |
| 06 | Heater Spacer | [`HeaterSpacer.stl`](HeaterSpacer.stl) | HTR |
| 07 | Pi 5 Mount | [`pi5mount.stl`](pi5mount.stl) | — |
| 08 | GPIO Breakout Mount | [`gpio_breakout_mount.stl`](gpio_breakout_mount.stl) | — |
| 09 | Heater Mount | [`my_heater_base_3holes.stl`](my_heater_base_3holes.stl) | HTR |
| 10 | Heater Circuit Holder | [`Heater_DFR0457.stl`](Heater_DFR0457.stl) | HTR |
| 11 | Temp Cutoff Ring | [`tempcut_combined_holder.stl`](tempcut_combined_holder.stl) | HTR |
| 12 | Switch Box | [`switchbox.stl`](switchbox.stl) | ☐ |
| 13 | Light Spacer Lower Ring | [`lightspacer_lower_ring_draft.stl`](lightspacer_lower_ring_draft.stl) | OPT |
| 14 | Cree Light Ring | [`Cree_lightring.stl`](Cree_lightring.stl) | OPT-LED |
| 15 | Light Spacer, Large | [`lightspacer_large.stl`](lightspacer_large.stl) | OPT |
| 16 | Light Circuit Hat | [`light_circuit_hat.stl`](light_circuit_hat.stl) | OPT-CTL |

IDs are stable labels assigned in order of addition, not assembly order.

### Also in this folder, not a numbered part

| File | What it is | Status |
|---|---|---|
| `lightspacer_lower_ring.3mf` | Bambu Studio project for **part 13** | ✅ Keep — a print-ready source artefact, which part 11 conspicuously lacks |
| `thermalcut_sensorholder.3mf` | Bambu Studio project for the **superseded** two-file part 11 workflow | ☐ **Review** — D-11 previously recorded this as deleted; it is still here. It is scaffolding for the merge-at-slice-time method that `tempcut_combined_holder.stl` replaced, so it is probably a delete — but it is also the only remaining artefact carrying part 11's pre-merge geometry (see the source-CAD warning in [D-11](#d-11-temp-cutoff-ring)) |

## Stack order

Bottom to top. Confirmed 2026-08-18 against the Fusion coordinates still carried in the STLs.

| | Part | Role |
|---|---|---|
| ▲ top | **03** LCD Carrier | mask carrier |
| | **04** Cone | dark chamber |
| | **05** Cone Spacer, 1 in | throw adjustment, stackable |
| | **01** Plate Holder | dish / sample stage |
| | **06** Heater Spacer | spacer between heater and dish holder — **11** nests inside it |
| | **09** Heater Mount | PTC heating element + DS18B20 insert |
| ▼ base | **10** Heater Circuit Holder | DFR0457 driver — the essential heater circuit, at the base |

Part **11** (temp cutoff ring) is not a stack layer: it snaps *inside* the bore of part 06.
Parts **02**, **07** and **08** are not in the column at all.

Parts 09 and 10 are both current and both part of the heater layer — 09 carries the PTC element, 10 carries the DFR0457 driver. The pre-rebuild heater circuit board mount is obsolete and not tracked here.

---

## 01 — Plate Holder

`Plate_Holder.stl` · 113.1 × 113.0 × 31.8 mm

Sample stage at the base of the frustum. Holds the agar plate at the focal plane.

| Spec | Value |
|---|---|
| Material | PETG — as with **every** part on this device; part 01 additionally needs it for the UV-resin sterilisation coating |
| Dish size | 90 mm or less |
| Seating | Raised off the bottom grid |
| Grid | Airflow passes under and around the dish for even passive heating |
| Air passage | Extends to the base of the model — **prints without supports** (rev 2026-08-17) |
| Volume | **64.35 cm³** — thickened to reach Z = 0; do not lighten (see [D-01](#d-01-plate-holder)) |
| Finish | Optional UV resin coating (PETG-specific) to seal print voids for sterilization |

[More details → D-01](#d-01-plate-holder)

---

## 02 — Lower Stage Sensor Mount

`lower_stage_sensor.stl` · 86.4 × 86.4 × 36.0 mm

Holds the AS7341 spectral sensor at substrate height for calibration runs.

| Spec | Value |
|---|---|
| Sensor seating | Sits on the protruding pin |
| Cable routing | Routes under the lower bar |
| Fasteners | None |

[More details → D-02](#d-02-lower-stage-sensor-mount)

---

## 03 — LCD Carrier

`LCD_Carrier_1.1_CF.stl` · 107.0 × 135.0 × 14.7 mm

Image mask carrier — sliding sled in the negative-carrier position. Revision 1.1.

> ⚠ **The file here is the single-piece rev 1.1.** The design has since been **split into two parts**
> — a **carrier body** and a **bezel plate** — refined for the 1.1″ T4 screen and CFA10110 mounting.
> **Neither of the two-part files is in this folder.** See the
> [LCD readme](../../spaceplacer_repo/projects/imaging/spaceplacer_lcd_display_readme.md).

**Two independent fastener systems** — do not conflate them:

| | Fastener | Into | Notes |
|---|---|---|---|
| **Bezel plate → carrier body** | **M2 × 5 mm** | **M2 heat-set inserts** in the print | ⏸ **PARKED 2026-08-22** — fastener resolved, but the bezel itself is on hold (see below) |
| **Carrier → CFA10110 driver** | **2 × #2-56 flat head, 3/16″** | The driver board's own standoffs | ✅ **Confirmed 2026-08-22 — countersunk heads clear the bottom.** Flat head required; no inserts, clearance holes only |

### ⏸ Bezel plate parked 2026-08-22

The bezel **still does not fit** the negative-carrier slot and the thickness tolerances are too tight
to keep iterating on the two-part geometry — **a simplified design is to be considered** instead. The
fastener numbers below are settled and stay on file for whatever replaces it.

**The driver mounting is unaffected and proceeds:** the #2-56 flat heads seat in their countersinks
and clear the bottom, so the CFA10110 can be mounted now. The two fastener systems are independent.

### Bezel fastener — resolved 2026-08-22

| Measured | Value |
|---|---|
| Bezel plate thickness | **2.61 mm** |
| M2 insert depth | **2.86 mm** |

```
M2 × 5 mm → 5.00 − 2.61 = 2.39 mm engaged  ≈ 1.2×D · 0.47 mm clear of bottom   ✅
M2 × 6 mm → 6.00 − 2.61 = 3.39 mm          BOTTOMS OUT by 0.53 mm              ⛔
M2 × 4 mm → 4.00 − 2.61 = 1.39 mm          = 0.7×D — too thin                  ⚠
```

A bottoming screw **pushes the insert out of the boss** rather than clamping the bezel — the same
failure [D-09](#d-09-heater-mount) flags for M3 × 6 mm in a 4 mm insert.

**Iron temperature for the M2 inserts: 240 °C**, same PETG working band (230–250 °C) as every other
insert on the device. Press with the guide tool — **never freehand**; a skewed insert cracks the
carrier and mis-seats the glass.

[More details → D-03](#d-03-lcd-carrier)

---

## 04 — Cone

`Cone.stl` · 104.5 × 104.5 × 152.4 mm

Dark chamber frustum. Light-tight envelope over the optical path.

| Spec | Value |
|---|---|
| Height | 152.4 mm (6 in) |
| Base | 104.5 mm OD / 100.5 mm ID |
| Top | 50.8 mm OD / 46.7 mm ID |
| Wall | 2.0 mm |

[More details → D-04](#d-04-cone)

---

## 05 — Cone Spacer, 1 in

`Cone_Spacer_1in.stl` · 108.5 × 108.5 × 31.8 mm

Stackable spacer ring. Adjusts throw distance between lens and substrate plane in 1 in increments.

| Spec | Value |
|---|---|
| Outside diameter | 108.5 mm |
| Inside diameter | 100.5 mm |
| Wall | 2.0 mm |
| Height | 31.8 mm overall; 25.4 mm (1 in) added throw |
| Register lip | 6.4 mm, nests over the cone base |

[More details → D-05](#d-05-cone-spacer-1-in)

---

## 06 — Heater Spacer

`HeaterSpacer.stl` · 113.1 × 113.1 × 30.5 mm

Stacking ring forming the heater chamber. Plain ring — contains no heater mounting hole and no sensor insert.

| Spec | Value |
|---|---|
| Outside diameter | 113.1 mm |
| Inside diameter | 105.1 mm |
| Wall | 2.0 mm |
| Height | 30.5 mm overall; 25.4 mm (1 in) added stack height |
| Register lip | 5.1 mm, nests into the ring above |
| Heater element | **PTCYIDU** PTC plate, 12 V, **45 W**, insulated aluminium shell, **77 × 62 × 6 mm** ([ASIN B0BNZRQP5Q](https://www.amazon.com/dp/B0BNZRQP5Q)) |

The heater mount proper — the part carrying the element and the DS18B20 insert — is [part 09](#09--heater-mount). See [D-06](#d-06-heater-spacer).

[More details → D-06](#d-06-heater-spacer)

---

## 07 — Pi 5 Mount

`pi5mount.stl` · 56.0 × 65.0 × 12.7 mm

**Mounts the Raspberry Pi 5 to the inside top of the device**, board hanging beneath.

| Spec | Value |
|---|---|
| Standoffs | **4**, ~6.35 mm square, **12.7 mm tall** (6.35 mm base + 6.35 mm post) |
| **Hole pattern** | **49.0 × 58.0 mm on centres** — matches the Pi 5 spec exactly |
| Chassis fixing | **1 × Ø3.9 mm hole, dead centre** (28.0, 32.5) |
| Board overhang | Pi 5 is 85 × 56 mm; the mount is 65 mm long, so the board overhangs ~20 mm |

☐ **How does the Pi fasten to the standoffs?** The posts read **solid — no bores**. Pi 5 uses **M2.5**
holes, so this needs self-tapping screws into solid posts, or M2.5 heat-set inserts added. Record which.
☐ **Single central bolt allows rotation.** Nothing in the part keys its angle — confirm the mounting
surface provides a locating feature, or add a second fastener.

[More details → D-07](#d-07-pi-5-mount)

---

## 08 — GPIO Breakout Mount

`gpio_breakout_mount.stl` · 130.4 × 25.4 × 31.8 mm

Rail mount for the **40-screw-terminal GPIO breakout**, fed by ribbon cable from the Pi 5 above.
**Sited left-front** for hand access to the terminals and short cable runs to each assembly.

| Spec | Value |
|---|---|
| Board fixing | **2 × Ø2.2 mm** (M2 clearance) at **57.15 mm** (2.25″) centres |
| Chassis fixing | **2 × Ø3.9 mm** at **103.44 mm** centres |
| Layout | All four holes in a single row |
| Terminals | 40 screw terminals — one per GPIO header pin |

**Why left-front matters:** every assembly lands here, so terminal access is the thing being optimised.
Screw terminals are re-worked far more often than soldered joints, and this is where harness changes
happen.

> ### ⚠ Orientation is the known failure mode on this part
> A **180°-reversed ribbon** once produced a complete false bring-up — every signal present, nothing
> where the pin map said it was. The mount is where that can be designed out.
>
> ☐ **Can this mount be fitted 180° out?** Its two chassis holes are symmetric about the centre, and
> its two board holes are also symmetric — so **nothing in the geometry prevents a reversed fit.**
> Add a keying feature, or mark pin 1 on the print itself (embossed, not a label).

[More details → D-08](#d-08-gpio-breakout-mount)

---

## 09 — Heater Mount

`my_heater_base_3holes.stl` · 113.0 × 113.1 × 31.8 mm

Holds the PTC heater element, carries the insert for the DS18B20 probe, and **passes all heater-zone
wiring down into the circuit module** (part 10) below.

> **Revised 2026-08-18 — `my_heater_base_v2` is superseded and deleted.** The floor now has
> **3 × Ø5 mm holes** in place of the previous two undersized slots. See [D-09](#d-09-heater-mount).

☐ **Filename does not follow the naming rule** — `my_heater_base_3holes` is a working name. Rename to
`Heater_Mount_v3.stl` when convenient.

| Spec | Value |
|---|---|
| Outside diameter | 113.1 mm; central bore Ø53.4 mm |
| Height | 31.8 mm |
| Hole pattern | 4 standoffs, 2.06 × 1.28 in on centers — **measured 52.33 × 32.51 mm** |
| Posts | Ø8.0 mm OD × 4.8 mm tall, from a 2.0 mm floor |
| Iron temperature | **240 °C** (PETG working range 230–250 °C) |
| Fasteners | 4 × M3 hex socket |
| Anchors | 4 × heat-set insert, M3 |
| Bore | 4.0 mm — provisional, allows for shrinkage; confirm once printed |
| Insert OD | 4.4 mm |
| Insert d1 (outer thread) | 3.8 mm |
| Insert thread length | 3 mm minimum |
| Insert source | FFVRVSS kit (Amazon) |
| Temp sensor | DS18B20 insert — 19.0 × 3.0 mm at the wall, rising z 2.0 → 26.6 mm |
| **Lead pass-throughs** | **3 × Ø5.0 mm** through the 2 mm floor, at y = −45.7, **11.0 mm pitch** (x = −11.0 / 0 / +11.0) |
| Wire routing | All heater-zone wiring drops through these into part 10 |

[More details → D-09](#d-09-heater-mount)

---

## 10 — Heater Circuit Holder

`Heater_DFR0457.stl` · 113.1 × 113.0 × 25.4 mm

**The essential heater circuit, at the base of the stack.** This is the holder that previously took
the soldered perfboard circuit; it now carries the DFR0457 driver on four heat-set-insert posts. The
PTC element (part 09) sits on top of it; neither supersedes the other.

| Spec | Value |
|---|---|
| Outside diameter | 113.1 mm |
| Height | 25.4 mm (1 in) |
| Floor | 2.0 mm, posts rise from it |
| Posts | 4, Ø8.0 mm OD × 4.0 mm tall (z 2.0 → 6.0 from floor) |
| Insert bore | Ø4.0 mm |
| Post pattern | **25.0 × 20.9 mm on centres**, offset from the ring axis |
| Anchors | 4 × heat-set insert, M3 — FFVRVSS kit (OD 4.4 · d1 3.8 · thread ≥ 3 mm) |
| Fasteners | 4 × M3 hex socket, 5 mm |
| Board carried | DFR0457, PCB 44 × 32 mm |
| Iron temperature | **240 °C** (PETG working range 230–250 °C) |

[More details → D-10](#d-10-heater-circuit-holder)

---

## 11 — Temp Cutoff Ring

`tempcut_combined_holder.stl` · 105.0 × 98.0 × 12.7 mm

Snap-in ring that retains the KSD9700 thermal cutoff **inside the bore of part 06**, not as a stack
layer of its own. 105.0 mm OD against the spacer's 105.1 mm ID.

> ✅ **Revised 2026-08-21 — now a single file.** `tempcut_combined_holder.stl` is the ring and the
> sensor pocket merged into one printable mesh, replacing the old load-two-files-and-merge-in-the-slicer
> workflow. **The composite caveat is retired.**
>
> 🗑 **Superseded halves deleted 2026-08-24** — `tempcut_ring.stl`, `tempcut.stl` and
> `tempcut_ring.step` are gone from the folder. They were reference only; the merged mesh is the
> single printable. ⚠ See D-11: this leaves part 11 with **no source geometry of any kind**.

| Spec | Value |
|---|---|
| Outside diameter | 105.0 mm — nests **inside** part 06's 105.1 mm bore |
| Height | 12.7 mm (0.5 in) |
| Retains | KSD9700 thermal cutoff, body ~20 × 7.75 × 3.6 mm |
| Fasteners | None — snap fit |
| Assembly | **Single mesh** — merged in CAD, not at slice time |
| Source | ⚠ **None** — the superseded halves were deleted 2026-08-24 and no STEP/F3D of the merged part exists (D-11) |

☐ **Superseded by design intent** — see D-11. A simplified spacer that holds the sensor *and* routes
its leads is planned, which would absorb this part and part 06 into one.

[More details → D-11](#d-11-temp-cutoff-ring)

---

## 12 — Switch Box

`switchbox.stl` · 96.0 × 76.0 × 70.0 mm

**Panel enclosure for the manual rail switches.** ✅ **First unit built 2026-08-21.** Measured from
the mesh: a **4 mm floor**, filleted sides, open underside (−Z ≈ 29 % solid), mostly-closed top
(+Z ≈ 66 %).

### Build notes from the first unit — 2026-08-21

| Finding | Action |
|---|---|
| **12 mm holes are too tight** for the threaded 12 mm switch bushing | **Open to Ø12.5 mm.** A 12 mm nominal thread needs clearance over its major diameter — fix in CAD, don't ream every print |
| Switch rocks in the panel | Add a **5/8″ thin locking washer** to stabilise |
| **The black/red ON-OFF plate and the red flip cap cannot both fit** the manufactured assembly | **Flip cap chosen.** Legend goes on the box instead — self-labelled |

☐ **Update the CAD to Ø12.5 mm** so the next print needs no reaming.
☐ **Record the self-label wording** for ON/OFF, and whether it is engraved, embossed, or applied.
Embossing into the print removes a label that can peel.
☐ Record the washer spec/source and the switchbox fastening scheme.

### ☐ Planned — "lighthouse" indicator mod

A raised indicator tower on top of the box, putting each power-state light next to the switch it
reports on, so switch and state read together.

| Circuit | Indicator | Means |
|---|---|---|
| **Heater** +12 V | **red** | that circuit is powered — **not** that it is heating |
| **Light** +15 V | **blue under white diffusion** | that rail is powered ⚠ **see the goggle warning in the NS-04 readme** |

Electrical specs live with each circuit — [heater readme](../../spaceplacer_repo/projects/heater_v2/spaceplacer_heater_v2_readme.md)
and [NS-04 readme](../../spaceplacer_repo/projects/cree_led/spaceplacer_ns04_blue_rail_ctrl_readme.md).

☐ Diffuser geometry, LED seat (3 mm / 5 mm / panel bezel), and lead routing down into the box.

---

## 13 — Light Spacer Lower Ring

`lightspacer_lower_ring_draft.stl` · 159.9 × 159.9 × 27.4 mm — **rev 2, drafted bore**

**Retaining ring for the light spacer** — it stops the spacer slipping down into the **enlarger
body**. **Press fit**, and **adjustable**: its height on the spacer sets how deep the spacer sits.

> ### 🔁 Rev 2 — 2026-08-24: drafted bore, because rev 1 slipped
> **Rev 1's straight Ø149.78 bore did not hold.** Against the spacer's Ø149.82 that was +0.04 mm
> diametral — 0.02 mm on radius, finer than FDM repeatability — so the fit landed wherever the print
> happened to land, and in practice it landed loose.
>
> **Rev 2 tapers the bore at a 1.00° half-angle** — Ø149.74 at the top, narrowing to **Ø148.79** at
> the bottom. Outside diameter is unchanged at Ø159.97, and the envelope is identical, so it drops
> straight into the same place.
>
> **The taper narrows downward, which is the load direction.** The spacer's weight pushes it *down*
> through the ring — into the narrowing bore — so the joint **self-tightens under exactly the load it
> exists to resist**. Rev 1 had no such behaviour: a straight bore that slips once slips further.

Measured from the mesh: 826 triangles, two Z levels, constant Ø159.97 OD, tapered bore.

| Spec | Value |
|---|---|
| Outside diameter | **159.97 mm**, constant |
| Bore — top | **Ø149.74 mm** |
| Bore — bottom | **Ø148.79 mm** |
| Bore draft | **1.00° half-angle**, narrowing downward |
| Wall | 5.12 mm (top) → 5.59 mm (bottom) |
| Height | **27.40 mm** |
| Fasteners | None — **press fit**, self-tightening under load |
| Adjustment | Ring position on the spacer sets the spacer's depth in the body |

✅ **Spacer OD resolved 2026-08-24** — it mates with [part 15](#15--light-spacer-large), whose lower
section is **Ø149.82 mm** straight. Against rev 2's tapered bore that is **+0.08 mm interference at the
ring's top, rising to +1.03 mm at its bottom** — a wedge, not a constant fit. The ring slides along **76.19 mm** of straight spacer, giving **48.79 mm** of
adjustable travel once its own 27.40 mm height is accounted for.

⏸ **That travel is the optical tuning range, in active use.** This part is currently a *tuning
fixture*: the emitter height is being set empirically for best projection convergence, and only then
will it be recorded and locked in — see [D-15](#d-15-light-spacer-large). Expect this ring to be
revised or replaced at lock-in; the fit that adjusts well is not the fit that holds permanently.

☐ **The enlarger body's opening is still unrecorded** — the 159.94 mm OD must not pass through it, or
the assembly drops and the part does nothing. That dimension lives on inherited hardware, not CAD.
**PETG**, per the device-wide rule at the top — and load-bearing here, since the retention is an interference fit that a softer filament would relax out of. ☐ Print orientation not recorded.
☐ Not placed in the stack-order table: it belongs to the light/optical path above the mask, not the
heater column.

[More details → D-13](#d-13-light-spacer-lower-ring)

---

## 14 — Cree Light Ring

`Cree_lightring.stl` · 174.6 × 174.6 × 42.9 mm

**Carrier for the Cree XP-E2 470 nm emitter array** — the lamphouse replacement that seats the light
source above the condenser. Largest part on the device.

Measured from the mesh: an outer **skirt** with a **web plate** across it, a central **hub**, and a
raised **ring** on top. 1,956 triangles, 6 distinct Z levels.

| Spec | Value |
|---|---|
| Outside diameter | **174.62 mm** |
| Skirt bore | **149.22 mm** |
| Skirt wall | **12.70 mm** — exactly 0.500 in |
| Skirt height | 32.20 mm (Z −12.70 → +19.50) |
| Web plate | **3.20 mm** thick (Z +9.80 → +13.00), spanning to the skirt bore |
| Central bore | **Ø9.97 mm** |
| Central hub | **Ø37.77 mm**, rising to Z +19.60 |
| Upper ring | Ø75.80 – Ø112.46 at Z +30.20 |
| Edge notches | 2 × ~1.76 × 3.59 mm at the plate rim, mirrored about X — ☐ purpose not recorded (cable exit? keying?) |

> ### ✅ RESOLVED 2026-08-24 — it mates with part 15
> The inferred Ø≈149 tube is real: it is [part 15](#15--light-spacer-large), added the same day. The
> skirt bore of **149.22 mm** seats on the spacer's **tapered top OD**, which passes through 149.26 mm
> at its narrowest. Both this joint and part 13's are cut to the **same +0.04 mm interference** — see
> [D-15](#d-15-light-spacer-large) for the full mating table. Nothing was wrong; the two close bores
> were two different stations on one tube.

Both this part and part 13 are walled in **exact imperial** (0.500 in and 0.200 in) while the rest of
the printed stack is metric — consistent with both being dimensioned against the inherited **Bogen
enlarger** hardware rather than the printed column.

☐ **Emitter mounting not recorded.** No mounting-hole pattern for the Cree stars, the heat sink, or
the fan was resolvable from the mesh at this level. Record how the array, sink and Carclo optics
attach, and to which surface.
☐ **Thermal path not recorded.** The Cree sink sheds **~3.3 W** into whatever carries it — see the
material rule; this part is squarely in the light path and must be PETG.

[More details → D-14](#d-14-cree-light-ring)

---

## 15 — Light Spacer, Large

`lightspacer_large.stl` · 149.7 × 149.8 × 92.1 mm

**The column that raises the Cree light ring to optical height** — setting the throw for projection
convergence. ⏸ **That height is deliberately tunable and not yet locked in:** the optimum is being
found empirically, then recorded, and the parts revised to suit. A plain tube with a **stepped/tapered outer diameter**, and it is the part that ties the
whole upper assembly together: [part 14](#14--cree-light-ring) wedges onto its top,
[part 13](#13--light-spacer-lower-ring) grips its lower section and stops it dropping into the
enlarger body.

| Spec | Value |
|---|---|
| Height | **92.07 mm** — ⏸ **provisional, tunable by design** (see [D-15](#d-15-light-spacer-large)) |
| Bore (clear aperture) | **Ø142.84 mm**, constant full height |
| Wall | **3.49 mm** |
| OD — lower, straight | **Ø149.82 mm** over **76.19 mm** |
| OD — upper, tapered | **Ø149.82 → Ø149.26** over the top **15.88 mm** (≈**1.0° half-angle**) |

### The fits — both cut to +0.04 mm

| Joint | Bore | Spacer OD | Interference |
|---|---|---|---|
| **14** Cree light ring → spacer top | Ø149.22 | Ø149.26 | **+0.04 mm** |
| **13** lower ring → spacer bottom | Ø149.78 | Ø149.82 | **+0.04 mm** |

Two joints, two stations on one tube, **the same interference at each**. The shallow top taper is a
**self-locking wedge**: the light ring starts easily at the narrow top and tightens as it is pushed
down, which both centres it on the optical axis and grips it without a fastener.

⚠ **+0.04 mm diametral is 0.02 mm radial — finer than FDM repeatability.** See
[D-15](#d-15-light-spacer-large): in practice your printer's calibration, not the model, decides
whether these come out tight, loose, or immovable.

[More details → D-15](#d-15-light-spacer-large)

---

## 16 — Light Circuit Hat

`light_circuit_hat.stl` · 149.2 × 149.2 × 42.1 mm

**Closed cap over the Cree light ring**, carrying the **NS-04 perfboard** that replaces the
breadboarded blue-rail CTRL circuit. Drops into part 14's bore as a spigot.

| Spec | Value |
|---|---|
| Outside diameter | **Ø149.23 mm** — into [part 14](#14--cree-light-ring)'s Ø149.22 bore |
| Seats on | part 14's web plate at **Z 13.00** |
| Height | **42.10 mm** (Z 13.02 → 55.12) |
| Clears | part 14's **10.66 mm** protrusion, out to Ø112.45 |
| **Wire porthole** | **Ø12.00 mm**, central — 4 wires + future wire-lock |
| **Standoffs** | 4 × **10 mm tall**, **Ø4.00 mm bore**, Ø10 → Ø13.52 flared |
| **Post pattern** | **35.00 × 55.00 mm**, centre offset **−33.20 mm in X** |
| Top plate | 4 mm (Z 51.12 → 55.12) |

### ⚠ ☐ The four standoff bores break through the top face

Verified from the mesh: the Ø4.0 bores span the full 10 mm, **Z 45.12 → 55.12**, and top-face material
starts at r = 2.00 mm around each post. **They are open.**

**That is four light leaks in the cap of a 470 nm lamphouse, pointing up at the operator.** The
[standoff standard](#heat-set-inserts--standoffs--device-standard) calls for a **6 mm blind bore with
2 mm of solid floor** — partly to avoid exactly this.

☐ **Shorten the bores to 6 mm**, leaving the 4 mm top plate solid — or plug them.
⚠ With a through-bore there is also **no bottoming limit**: a long bolt simply exits the top, so the
bolt-length table stops protecting the insert.

### ⚑ Perfboard mounting is M2 — resolved by drilling, once

The posts were modelled at **Ø4.0 for M3** before the perfboard was offered up. **Perfboard mounting
holes are M2-sized and an M3 bolt does not fit.**

**Resolved for this part by drilling the perfboard to Ø3.4 mm (M3 free fit)** rather than reprinting,
since the print was already under way. ⚠ **That is a one-off remedy, not the standard** — design new
perfboard-carrying parts to **M2 (bore Ø3.0, post Ø7.0, M2 × 5)** from the first sketch.

☐ Confirm the 35.00 × 55.00 pattern matches the board's actual holes, and that the **33.20 mm
off-axis offset** is deliberate (it keeps the board clear of the central porthole).

### ☐ Planned — wire-management cap

Two snapping halves with a fitted cable sleeve, acting as a passthrough tension manager on the Ø12
porthole. **Needed, not cosmetic:** the NS-04 build uses **male Dupont pins soldered directly into the
perfboard**, which have **no strain relief** — the solder joint itself takes any cable pull.

### Venting — deliberately not here

Vents belong in [part 15](#15--light-spacer-large), the 92 mm tall volume directly enclosing the
emitter and heat sink where heat actually accumulates. The hat sits above it and mostly sees what
rises. Decided 2026-08-26.

---

## Heat-set inserts & standoffs — device standard

Iron at **240 °C** for every insert on this device, M2 and M3 alike (PETG working band 230–250 °C).
Press **square and slow** so the melt flows rather than skins — **use the guide tool, never freehand**.

| | **M3** | **M2** |
|---|---|---|
| Source | FFVRVSS kit | ☐ measure your kit |
| Insert OD | 4.4 mm | ~3.2 mm |
| Insert d1 | 3.8 mm | ~2.8 mm |
| **Receiving bore** | **Ø4.0 mm** | **Ø3.0 mm** |
| Post OD (2 mm wall) | Ø8.0 mm | Ø7.0 mm |
| Post height / bore depth | 8 mm / 6 mm | 8 mm / 6 mm |
| Solid floor under bore | 2.0 mm | 2.0 mm |
| **Bolt for a 1.5 mm board** | **M3 × 6** | **M2 × 5** |
| Engagement | 3.0 mm = 1.0×D | 3.0 mm = 1.5×D |
| Max bolt before bottoming | 7.5 mm | 7.5 mm |

**Bore sizing rule:** sit just **above d1** so the knurl clears and enters, well **under OD** so it still
bites. Sized to OD the insert drops in and spins; far under d1 the boss splits.

⚠ **Printed bores come out undersized** — expect ~0.1–0.2 mm under nominal. Measure the first print.
**At or above 4.2 mm (M3) / 3.4 mm (M2) the inserts will spin** — tighten in CAD, do not compensate at
install.

⚠ **A bottoming bolt pushes the insert out of the boss** instead of clamping the part. Engagement is
capped by the insert's ~3 mm thread, not by bore depth: a longer bolt buys clearance, not grip.

> ### ⚑ Perfboard mounting is M2, not M3 — learned 2026-08-26
> **Perfboard mounting holes are M2-sized; an M3 bolt does not fit.** The M3 standard above is right
> for *printed-part-to-printed-part* and for module mounts (parts 09, 10), but **any standoff that
> carries a perfboard must be M2**.
>
> This surfaced on [part 16](#16--light-circuit-hat) after its posts were already modelled at Ø4.0.
> **Resolved for that part by drilling the perfboard out to Ø3.4 mm (M3 free fit)** rather than
> reprinting — the print was already under way. That is a one-off remedy, not the standard.
>
> **Design new circuit-carrying parts to M2 from the start.** When drilling out instead: back the board
> with scrap wood (FR4 breaks out on exit), step up rather than jumping to final size, deburr both
> faces, and check edge margin — a torn mounting hole near an edge is unrecoverable.

---

## Print settings

| Setting | Value |
|---|---|
| Material | **PETG — every part, no exceptions** (see the material rule at the top). PLA is not suitable anywhere on this device |
| Layer height | 0.20 mm — 0.16 mm for part 03 |
| Walls | 3+ |
| Infill | 20–30% |
| Supports | As needed, check after orienting — part 01 needs none |

Models carry their original Fusion 360 coordinates and sit below Z = 0. Drop to the build platform before slicing.

---

## Naming

`Part_Name.stl`, with a revision suffix where a part has iterated (`_1.1`) and a material suffix where the print targeted a specific filament (`_CF`). Superseded revisions are replaced — git history holds the older geometry.

---

## Related documentation

- [Chapter 3 — Wavelength Sensor](../docs/photoplasm_ch03_wavelength_sensor.md)
- [Chapter 6 — Incubation Heater Perfboard](../docs/photoplasm_ch06_heater_perfboard.md)
- [Appendix B — Feature Specification](../docs/appendix_B_feature_specification.md)
- [Quickstart Introduction](../docs/photoplasm_quickstart_intro.md)

---
---

# More Details

Rationale, reference data, and open items. Nothing here overrides the specifications above.

## D-01 Plate Holder

### Why PETG, not PLA

The holder sits in the thermal path of the incubation heater and is held at the 37 °C setpoint for the full duration of a run — hours at temperature, under the load of the dish.

PLA's glass transition is roughly 55–60 °C, and it softens and creeps under sustained load below that; it does not need to reach melting to sag. PETG's is roughly 80 °C, clearing the operating range with margin.

The margin is thinner than the setpoint suggests. The DS18B20 reads culture-zone temperature, not heater surface temperature (Ch. 6, Ch. 7), so surfaces nearer the element run hotter than the reported 37 °C.

Deformation is not cosmetic here. The holder sets the plate's position at the focal plane; a holder that sags mid-run moves the substrate out of focus and changes delivered irradiance, corrupting the exposure against its calibration. A PLA holder may survive a short run and fail on a long one — invalidating results before it visibly breaks.

### Grid and airflow

Raising the dish off the grid opens a gap that lets air pass evenly under and around the dish, so heat rising from the heater element reaches the sample from all sides rather than conducting into one contact face. This is the passive-heating path that holds the culture at 37 °C without a separate incubator.

Anything that blocks the grid apertures or closes the standoff gap defeats this — including over-thick surface coating.

### Air passage revision — 2026-08-17

**The first build needed supports, and that was the problem.** Support material printed *inside the
airflow grid* — the one place it must not be. It **clogged the airflow pattern** the grid exists to
provide, and it was **very hard to remove**: awkward to reach, and anything missed stays as a partial
blockage in the passage.

**The fix was to thicken the airflow pattern so it reaches Z = 0.** With the geometry carried down to
the build plate there is nothing to overhang, so the part prints support-free.

> ### ⚠ The revision ADDED material — do not "optimise" it back
> An earlier note here said the revision *removed* geometry. **That is wrong, and the meshes prove
> it.** Measured from the two exports (both closed and manifold, so the volumes are reliable):
>
> | | Aug 16 — pre-revision | **Aug 17 — current** |
> |---|---|---|
> | Volume | 33.27 cm³ | **64.35 cm³** |
> | Triangles | 7,836 | **7,428** |
> | Envelope | 113.05 × 113.00 × 31.75 mm | *unchanged* |
>
> **~93 % more material, in the same envelope, with fewer triangles.** The mass is not waste — it *is*
> the fix. Thicker struts running to the plate are what removed the supports, and they gave a thicker
> base as a bonus. Lightening this part reintroduces the overhangs, the supports, and the clogged
> grid. The simpler tessellation is the tell: fewer overhang features to describe.
>
> Pre-revision geometry is recoverable at `2554f8fc` — kept for reference only, **not printable
> without supports**.

Two further benefits follow. A passage open to the base has no enclosed underside to trap
contaminants, which suits the sterilization requirement below and makes the resin coating easier to
apply and inspect.

**Print this part without supports.** If a slicer proposes them here, the orientation is wrong — check
it before accepting, because supports in this grid defeat the part's function, not just its finish.

### Resin sealing

UV-cure resin formulated for PETG seals the voids and layer lines inherent to FDM printing, which would otherwise trap contaminants.

- Keep grid apertures and dish standoffs clear — pooled resin closes the airflow path.
- Coating adds thickness; confirm the dish still seats at the intended height, since seat height sets the under-dish gap.
- Cure fully before biological use. Uncured resin is a contaminant and cytotoxic.

### Sterilization limits

Sealed or not, this is PETG — glass transition roughly 80 °C, below the 121 °C of a steam autoclave. Autoclaving will deform the holder and change plate position at the focal plane. Sterilization means chemical: IPA, bleach, or a comparable cold method compatible with the cured resin.

### Open items

- Standoff height and resulting under-dish air gap not measured.
- Resin product not recorded; cure behavior and chemical resistance vary by formulation.
- Whether dishes smaller than 90 mm stay centered is unrecorded.
- Appendix B records the OPT-03 target as an 84 mm agar plate; the holder's working limit is 90 mm. One of the two should be updated.

## D-02 Lower Stage Sensor Mount

### Fastener-free by design

The sensor goes in for calibration and comes out before the biological substrate is placed, so it seats and lifts off the pin by hand between runs. See Stage 5 in the [quickstart introduction](../docs/photoplasm_quickstart_intro.md).

### Cable routing

Route the cable under the lower bar before seating the sensor, not after. Cable dressed over the bar can lift or tilt the board on its pin, changing the sensor's height and angle at the substrate plane — the exact quantity the calibration sweep measures. A sensor that shifts between runs invalidates comparison against earlier step-wedge data.

### Open items

- Pin diameter and height not recorded; needed to confirm fit against the AS7341 breakout's mounting hole.
- Whether the pin constrains rotation or only position is unrecorded.
- Sensor height relative to the plate surface — the number that makes the mount a valid substrate-plane proxy — not measured.

## D-03 LCD Carrier

### Why flat head is required

Carrier clearance inside the device is tight, so screw heads must sit flush with or below the carrier surface. A pan, button, or socket head protrudes and will foul the sled travel. Do not substitute.

Length matters in both directions. Flat head length is measured overall, head included, so 3/16 in spans carrier thickness plus thread engagement into the standoff. A longer screw either bottoms out in the standoff before the head seats — leaving the head proud, defeating the clearance requirement — or protrudes past the standoff on the far side.

### Fastener reference

#2-56 UNC: major diameter 0.086 in (2.18 mm), 56 TPI. ANSI flat head is an 82° countersink, head diameter up to 0.172 in (4.4 mm).

Metric M2 flat head (90° countersink, 3.8 mm head) is not a drop-in substitute — it will not seat flush in an 82° countersink, and the thread pitch is wrong for the standoffs.

Screws pass through the carrier into the driver board's standoffs; **for the driver mounting** nothing is tapped into the print and no inserts are involved. Carrier holes are clearance holes, not tapped: #43 (0.089 in / 2.26 mm) close fit, #38 (0.1015 in / 2.58 mm) free fit.

**Corrected 2026-08-22:** an earlier version of this line said the part uses *no* heat-set inserts at all. That is true only of the **driver** mounting. The two-part design adds **M2 heat-set inserts in the carrier body** for the bezel plate — see §03 above.

### Why the bezel exists, and why torque is different here

The bezel plate clamps the screen at its **edge/face perimeter**, so the fragile glass is never slid into a slot. That is a direct response to a screen destroyed by exactly that: sliding it into a friction slot.

Which makes the bezel screws the one fastener on this device where **the print is not the weakest part** — the glass is. **Snug by feel only.** The screen cracks long before M2 brass strips, so the "tighten until it stops" habit that is safe on a board standoff is wrong here. Tighten in a **diagonal cross pattern** in small increments so the bezel lands flat and never loads a single corner.

### Print note

The countersink is a functional feature. Check it for elephant foot or first-layer squish if the carrier prints face-down, and test-seat a screw before assembly — a head sitting even 0.5 mm proud eats the clearance budget.

The `_CF` suffix denotes the carbon-fiber-filled filament the part was designed against. It prints in plain PETG, with slightly more flex in the sled.

### Open items

- ⏸ **Bezel plate PARKED 2026-08-22** — still does not fit, tolerances too tight; consider a simplified design. Items below that concern the bezel are held with it.
- ✅ **#2-56 flat heads + countersink clear the bottom (2026-08-22)** — driver mounting good to assemble.
- ✅ Bezel thickness (2.61 mm) and M2 insert depth (2.86 mm) recorded → **M2 × 5 mm**.
- ☐ **The two-part files are not in this folder** — only the superseded single-piece rev 1.1. Upload the carrier body and bezel plate (STL + STEP/3MF).
- ☐ **Bezel screw head type** — the bezel is the sled's outward face, so a pan or button head can foul travel, the same constraint that forced flat heads on the driver screws.
- ☐ Standoff height and carrier thickness for the **2-56 driver screws** still not recorded — together they must equal the 3/16 in the screw provides.
- ☐ Insert count around the perimeter not recorded.
- Torque/seating notes pending first assembly.

## D-04 Cone

### Dimensions do not match Appendix B

Measured profile: 152.4 mm tall (6 in), 2.0 mm wall, base 104.5 mm OD / 100.5 mm ID, top 50.8 mm OD / 46.7 mm ID.

Appendix B records OPT-01.1 as a 256 mm frustum with a 51 mm top ID and 152 mm base OD. The top matches — 50.8 mm, though that is the OD, not the ID. Height and base diameter do not: 152.4 mm against 256 mm, and 104.5 mm against 152 mm.

152.4 mm is exactly 6 in, matching the lower end of the documented 6–12 in throw range, and the base nests into the spacer's register lip (part 05). That is consistent with the cone being the base segment extended by spacers, but it is an inference, not a recorded fact.

### Open items

- Reconcile against Appendix B OPT-01.1, and correct whichever record is stale.
- Confirm whether this is the complete cone or a segment.

## D-05 Cone Spacer, 1 in

### Nominal vs measured height — resolved

The file is named for a 1 in increment and measures 31.8 mm overall, which looked like a 0.25 in discrepancy. Measuring the profile resolves it: the body spans 25.4 mm exactly, and the remaining 6.35 mm is a register lip that nests into the part above rather than adding to the stack.

Each spacer therefore adds a true 1 in of throw. The name is correct and the throw-distance calculation is unaffected.

Profile: 108.5 mm OD, 100.5 mm ID, 2.0 mm wall. The lip's 52.27–54.27 mm radius band seats over the cone's 50.24–52.27 mm base — the two nest directly.

Appendix B records OPT-01.2 as a 50 mm spacer, which this is not. Either a second spacer size exists or the spec is stale.

### Open items

- Maximum stackable count not recorded.
- Reconcile against Appendix B OPT-01.2.

## D-06 Heater Spacer

### This file is not the heater mount

Measured from the mesh, `HeaterSpacer.stl` is a ring of revolution with no features at all beyond its stacking profile — every vertex falls at one of three radii (52.53, 54.53, 56.53 mm) across four Z planes. There is no heater mounting hole, no pocket for the element, and no DS18B20 insert in this geometry.

Profile: 113.1 mm OD, 105.1 mm ID, 2.0 mm wall, 30.5 mm overall, with a 5.1 mm register lip that nests into the ring above. Added stack height is 25.4 mm (1 in), matching the ~1 in modular ring described in [Chapter 6](../docs/photoplasm_ch06_heater_perfboard.md).

The heater mount carrying the element and the sensor insert is a separate part, not present in this folder.

### Heater element

**PTCYIDU PTC plate, 12 V, insulated aluminium shell** — [ASIN B0BNZRQP5Q](https://www.amazon.com/dp/B0BNZRQP5Q). Vendor spec table recorded 2026-08-18; all power/current figures carry ±20 %.

| | |
|---|---|
| Dimensions | **77 × 62 × 6 mm (±1)** |
| Max power | **45 W** → ~3.75 A |
| Power without airflow | **7 W** → ~0.58 A |
| Inrush current | **≤ 8.5 A** |
| Resistance range | 1–4 Ω |
| Surface temp, no airflow | 70 °C |
| **Chip temperature** | **TS80** — 80 °C Curie point |
| Leads | 15 cm high-temp, non-polar, tensile > 5 kg |

> **Corrected:** this file previously recorded **50 W / ~4.2 A**, taken from the listing title. The vendor spec table says **45 W**, matching the heater readme's original figure.

**The thermal margin is thinner than this file used to claim.** 70 °C is the *surface* temperature in still air, measured hung in a windless space at 24 °C ambient (±10 °C per the vendor's own note). The **chip** is TS80 — an 80 °C Curie point, which is PETG's glass transition, not 10 °C below it. Screw and heat-set insert form a metal path from element into the print ([D-09](#d-09-heater-mount)), so the plastic at each insert is the hottest plastic in the assembly. The 55 °C KSD9700 is the real bound on a runaway; do not treat the element's self-limiting as the safety layer.

It still sharpens the PLA prohibition on part 01: PLA's glass transition of 55–60 °C sits *below* the element's normal operating range, so a PLA part in the thermal path can be driven past softening by the element working exactly as designed — no fault condition required.

**Steady-state power is airflow-dependent**, from 7 W in still air to 45 W with good dissipation, so the running current in this chamber has to be measured rather than assumed. **Inrush is ≤ 8.5 A**, which is what sizes the supply — see the heater readme's [§2.1a](../../spaceplacer_repo/projects/heater_v2/spaceplacer_heater_v2_readme.md).

### Temperature sensor insert

The heater mount includes the insert for the DS18B20 probe. Chapter 6 notes the probe reads culture-zone temperature rather than heater surface temperature; the insert's position is what enforces that distinction, so it is a calibration-relevant feature rather than a convenience.

Wiring and troubleshooting for the probe: [Appendix D](../docs/appendix_D_ds18b20_troubleshooting.md).

### Open items

- The obsolete pre-rebuild heater circuit board mount is not uploaded. (The heater mount itself is part 09, `my_heater_base_v2.stl`.)
- Insert dimensions and probe retention method — friction fit, adhesive, or captive — not recorded.
- ✅ Element dimensions recorded: **77 × 62 × 6 mm**.
- **☐ The element is larger than part 09's Ø53.4 mm bore and spans it** — 77 × 62 mm plate over a 53.4 mm hole. The four M3 posts sit at r = 30.9 mm, i.e. *inside* the plate's footprint (half-extents 38.5 × 31 mm). **The vendor spec lists no mounting holes.** So either the plate has holes the listing does not mention, or the posts carry a clamp plate/bracket over the element rather than bolts through it. **Resolve before printing another mount.**
- Chapter 6 records the element as a "PTCYIDU ceramic disc, 5V–12V". Brand is right, form factor is not — the part is a 77 × 62 mm plate, 12 V only. That component-list line is stale.

## D-07 Pi 5 Mount

### Footprint is smaller than the board

The Raspberry Pi 5 board is 85 × 56 mm. This part measures 56 × 65 mm — matching the board's width but falling short of its length, so it is likely a partial bracket or a two-point mount rather than a full-footprint tray. Unconfirmed.

### Correction — this is not a partial bracket

An earlier note here read the 56 × 65 mm outline against the Pi 5's 85 × 56 mm board and inferred a
partial or two-point bracket. **Measuring the mesh disproves that:** four standoffs sit on a
**49.0 × 58.0 mm** rectangle, which is the Pi 5's full four-hole pattern. The outline is smaller than
the board simply because the board overhangs — all four mounting points are carried.

### ⚠ The inside top is the device's hot zone

The Pi hangs from the **inside top**, which is where the device's heat collects. Two sources converge
there:

- The heater's convective column **exits at the top** by design — that is the airflow path the
  chamber depends on ([D-06](#d-06-heater-spacer)).
- The Cree LED and its **DLH-3up-EH heat sink** shed ~3.3 W near the top of the optical stack.

A Pi 5 throttles around 80–85 °C junction and is not a cool part unloaded. It is now sited in the
exhaust of a 70 °C element and beside an LED heat sink.

☐ **Measure the Pi's thermals during a sustained 37 °C hold**, not just at idle — `vcgencmd
measure_temp` alongside the heater staircase run. This is cheap to check and expensive to discover
after the enclosure is closed.
☐ Confirm the mount does not block the exhaust path it sits in.
### 🔭 Cooling approach — heat sink + Pi fan *(direction set 2026-08-21)*

The enclosure fan is **deferred**; the focus is a **heat sink and the Pi's own fan** instead. That is
a much cheaper path — it needs no vents, so **no HEPA filter, no light traps, and no re-measure of the
heater's running current**, all of which an enclosure fan would have forced.

Two consequences to design around.

#### ⚠ An internal fan does not remove heat from the enclosure

It moves heat **off the SoC into the enclosure air**. In a closed box the total heat load is
unchanged — the Pi's watts still end up in the chamber the heater is regulating. Strictly, active
cooling *improves the thermal coupling* between the Pi and the chamber air, so it can deliver Pi heat
to the chamber **faster** than a passive sink would.

| Goal | Does heat sink + Pi fan achieve it? |
|---|---|
| Stop the Pi throttling | ✅ Yes — this is the right tool |
| Reduce heat reaching the 37 °C chamber | ❌ **No.** Same watts, better distributed |

So if the ambient evaluation shows the *chamber* running hot from parasitic electronics heat, this
does not fix it — only ducting, relocating, or exhausting the sources does.

#### ⛔ The official Pi 5 Active Cooler competes for this mount's holes

The Active Cooler retains itself with **spring push-pins through the Pi 5's mounting holes** — the
same **49 × 58 mm** holes this mount's four standoffs use. They cannot both occupy the same holes.

☐ **Resolve before printing another mount.** Options: an **adhesive heat sink** that does not use the
mounting holes; letting the cooler take two holes and the mount the other two (diagonal pair); or
re-working the standoffs around the cooler's pins.

☐ **Note the intake-air problem.** Mounted to the inside top, the Pi hangs component-side-down, so the
cooler sits **beneath** the board — directly in the rising exhaust of the heater column. Its intake is
then the hottest air in the enclosure, which is exactly what caps an active cooler's performance.
Worth measuring before assuming the cooler solves it.

☐ The Pi 5's 4-pin JST-SH fan header drives PWM + tach under OS control, so **no GPIO is consumed**
and nothing needs adding to the framework pin map.

#### 🔭 Option under consideration — move the Pi outside the enclosure

**Removes the watts instead of managing them**, which beats both fan options: no Pi heat in the
chamber at all, the inside-top space is freed, and the Active-Cooler hole conflict above disappears.

Costs to weigh if it is taken:

- **The 40-way ribbon has to leave the enclosure** — another pass-through, and another **light leak**
  in a light-tight envelope. Needs the same baffle treatment a vent would have needed.
- **Ribbon length hurts signal integrity.** The LCD runs **7-wire SPI** and the DS18B20 runs 1-Wire;
  both degrade on a long unshielded ribbon. Keep it as short as the placement allows and re-verify
  the LCD and probe after moving.
- **This mount (part 07) becomes obsolete or needs redesigning** for an external position.
- **Reversed-ribbon risk rises** — a longer external ribbon is easier to seat backwards, and that
  already cost a full false bring-up once. Key it (see part 08's orientation warning).

### Open items

- Standoff fastening method — posts are solid, Pi 5 needs **M2.5**.
- Single central chassis bolt permits rotation; confirm a locating feature exists.

## D-08 GPIO Breakout Mount

### Open items

- ✅ Rail-style mount confirmed; hole patterns measured.
- Breakout board make/model not recorded — only that it has **40 screw terminals**.
- Ribbon cable length/type not recorded.
- ☐ **Anti-reversal keying** — see the orientation warning above.
- ☐ Whether the chassis holes take M3 or #6 not recorded (Ø3.9 mm clearance suits either).

## D-09 Heater Mount

**The part is `my_heater_base_3holes.stl`** — identified 2026-08-18 by measuring the mesh. It
is a *different part* from part 10 (`Heater_DFR0457.stl`): 09 carries the PTC element on a
52.3 × 32.5 mm pattern, 10 carries the DFR0457 driver board on a 25.0 × 20.9 mm pattern. Both are
current; neither supersedes the other.

### Fastening scheme

The heater element is held down with M3 hex socket screws threading into heat-set inserts installed in the printed mount. This is the opposite arrangement to the LCD carrier (part 03), which threads into standoffs already on its board — here the print itself carries the threads, via brass.

Inserts are from the FFVRVSS kit: 4.4 mm OD, 3.8 mm d1 outer thread, 3 mm minimum thread length.

### Hole pattern

Four standoffs on a 2.06 × 1.28 in rectangle (52.3 × 32.5 mm) on centers. Corner-to-corner diagonal is 61.6 mm, comfortably inside the 105.1 mm bore of the heater chamber ring (part 06), so the pattern clears the chamber wall with room for the boss diameters.

**Measured from the mesh: 52.33 × 32.51 mm**, post centres at (±26.16, +16.50 / −16.01) — the spec is
confirmed in the print. Posts are Ø8.0 mm OD with a Ø4.0 mm bore, 4.82 mm tall from a 2.0 mm floor,
so there is 2.0 mm of wall around each insert.

### Boss hole sizing

Four bores, documented at 4.0 mm.

The receiving hole is the number that decides whether the inserts hold. Sized to the 4.4 mm OD, the insert drops in and spins; sized far under the 3.8 mm d1, material has nowhere to displace and the boss splits. 4.0 mm sits between the two — above d1 so the knurl has clearance to enter, under the OD so it still bites — and leaves room for the printed hole to come out under nominal, which is the usual direction for a small bore in PETG.

The figure is provisional pending a printed part. Holes this size typically print undersized, so the effective bore may land nearer 3.8–3.9 mm; that is still workable, but it is the measurement to take first. If it comes out at or above 4.2 mm, the inserts will spin and the bore wants tightening in CAD rather than compensating at install.

Boss walls need enough material around the hole to contain the melt; a 4.4 mm insert wants a boss noticeably wider than the insert itself.

### Installation

Heat-set inserts go in with a temperature-controlled iron — **set it to 240 °C** for PETG (working range 230–250 °C) — pressed square and slowly enough that the melt flows rather than skins. An insert that goes in cocked will hold the heater at an angle, which matters here because the element's contact with the mount is the thermal path.

### Lead pass-throughs — revised 2026-08-18

The floor carries **three Ø5.0 mm through-holes**, at y = −45.7 on an 11.0 mm pitch. This replaced the
previous **two** slots of roughly 3.8 × 2.8 mm. Two changes, each for its own reason:

**Enlarged to 5 mm, because the old holes damaged the wire.** The PTC leads did not pass cleanly
through the undersized slots, and forcing them **stripped the insulation**. That is not a fit problem,
it is a fault waiting in a heated chamber: the PTC draws up to 3.75 A running and ≤ 8.5 A on cold-start
inrush, and bare conductor
against another lead or against a heat-set insert is a short. The mitigation is **heat-shrink,
colour-coded** — which was the plan for identification anyway, and now does double duty as abrasion
protection.

> ⚠ **Inspect, do not merely re-sleeve.** Any lead that was already pulled through the old slots may
> be nicked under intact-looking insulation. Sleeving hides that rather than fixing it. Ring out each
> conductor and inspect the jacket over the passed length before reuse.

**A third hole, because the cutoff had nowhere to go.** The KSD9700 sits in the spacer above
([part 11](#11--temp-cutoff-ring)) and has two leads that must reach the supply. The third hole lets
it be **wired from inside the heat chamber** and dropped down. All heater-zone wiring now converges
into the circuit module (part 10) at the base, where the circuit wiring is actually made — one
termination zone instead of leads escaping the stack at several heights.

☐ **Chamfer or deburr the hole mouths.** A printed hole edge is exactly what abraded the insulation
the first time; 5 mm of clearance helps, but a sharp layer edge at the rim still cuts.
☐ **Size the clearance against the sleeved OD**, not the bare wire — heat-shrink adds diameter, and
the cutoff pair shares one hole.

### Thermal note

Screw and insert together form a metal path from the aluminum-shelled element into the print. The element self-limits at 70 °C, below PETG's ~80 °C glass transition, so the bridge is not a failure risk — but the plastic immediately around each insert is the hottest plastic in the assembly, and heat-set inserts hold by melted grip. Worth checking retention after the first sustained run at setpoint.

### Open items

- Measure the as-printed bore against the 4.0 mm nominal and confirm insert retention.
- Screw length not recorded.
- Insert overall length not recorded — only the 3 mm minimum thread.
- DS18B20 probe retention method not recorded (the insert measures 19.0 × 3.0 mm, 24.6 mm tall).
- **☐ The probe insert is at y +41.3; the three pass-throughs are at y −45.7, on the opposite side.**
  The three holes are spoken for — two PTC leads and the cutoff pair. Does the DS18B20 lead need a
  route down as well, or does it exit the module another way?
- Element outline dimensions not recorded — the hole pattern is fixed, but the element's footprint sets the clearance around it.
- Rename `my_heater_base_3holes.stl` to match the naming rule.
- Source CAD (F3D/STEP) not tracked, and the `.3mf` went with the superseded version.
- Chamfer/deburr state of the new Ø5 mm holes not recorded — see the insulation note in D-09.

## D-10 Heater Circuit Holder

### What this part is

`Heater_DFR0457.stl` is the **current heater module** — the 1 in stack ring at the heater layer,
carrying the DFR0457 driver on four heat-set-insert posts.

Part 09 (`my_heater_base_v2.stl`) is a **different, equally current** part: it carries the PTC element
and the DS18B20 insert on a 52.3 × 32.5 mm pattern. The two are not interchangeable and neither
supersedes the other — 09 holds the element, 10 holds the driver that switches it. Both take the same
M3 inserts and both have Ø8.0 mm posts with Ø4.0 mm bores.

### Measured geometry

Taken from the mesh, not from CAD:

| | Value |
|---|---|
| Envelope | 113.05 × 113.04 × 25.40 mm |
| Ring OD | 113.05 mm (radius 56.53) — matches the rest of the stack |
| Floor | 2.0 mm |
| Post OD | **8.0 mm** |
| Post height | 4.0 mm (z 2.0 → 6.0 measured from the underside) |
| Insert bore | 4.0 mm through the post |
| Post centres | (−13.14, +3.99) · (+11.87, +3.99) · (+11.87, −16.89) · (−13.14, −16.89) |
| Pattern | **25.01 × 20.88 mm** on centres |
| Pattern centre | (−0.64, −6.45) — offset from the ring axis, not concentric |

The 8.0 mm post OD leaves 2.0 mm of wall around a 4.0 mm bore, which is enough material to contain
the melt around a 4.4 mm insert — it is a light interference, so press slowly and watch for the boss
bulging rather than the insert sinking.

### Iron temperature

**240 °C**, the working figure for these PETG posts. The band is 230–250 °C: below it the plastic
does not flow and the post cracks under pressure; above it the insert sinks too fast to keep square
and the plastic degrades. Stop with the flange flush, and let it cool fully before threading a bolt —
PETG near its 80 °C Tg has no strength and an insert torqued warm spins permanently.

### Open items

- Confirm the 25.01 × 20.88 mm pattern against the DFR0457's actual mounting holes — the pattern was
  measured from the print, and DFRobot publishes board outline only.
- Measure the as-printed bore. At or above 4.2 mm the inserts spin; tighten in CAD, not at install.
- Confirm screwdriver access to the VIN / GND / VOUT terminal block with the board seated.
- Source CAD (F3D/STEP) not tracked.
- Register lip / stacking profile not characterised here.

## D-11 Temp Cutoff Ring

### Why it is a separate part

The ring exists **so the cutoff's position can be adjusted.** The KSD9700 has to sit where it will
trip on a genuine runaway but not during a normal hold at 37 °C, and that spot is found empirically —
[the heater how-to validates it at step 36](../../spaceplacer_repo/projects/heater_v2/spaceplacer_heater_v2_howto.md).
Keeping the sensor in a separate snap-in ring means moving it is a reprint of a small 0.5 in ring
rather than of the whole spacer.

### ✅ No longer a composite — resolved 2026-08-21

`tempcut_combined_holder.stl` is a **single merged mesh**: 105.03 × 97.96 × 12.70 mm, the ring plus
the sensor pocket in one file. Slice that one file and you get the whole part.

Previously the two halves were joined **in Bambu Studio at slice time**, so `tempcut_ring.stl` alone
yielded a plain ring with no sensor retention. That trap is gone.

**Folder cleaned 2026-08-21.** The 8 `(Assembly)_BodyN` exports were removed once the merged mesh
existed — they were scaffolding for a workflow the combined file replaces.

**Superseded halves deleted 2026-08-24.** `tempcut_ring.stl`, `tempcut.stl` and `tempcut_ring.step`
are no longer in the folder. They were reference only — never printables — and their exports were not
co-located anyway (the ring sat at z −1131, the pocket at z 0), so they were a standing trap for
anyone reading those coordinates as stack positions. Nothing printable was lost.

> ### ⚠ ☐ Part 11 now has NO source geometry — the merged STL is the only artefact
> This was already thin and the 2026-08-24 cleanup closed the last door. `tempcut_ring.f3d` was
> deleted earlier; the removed 3MF referenced a `tempcut_ring_parts.step` that was never in this
> folder; and `tempcut_ring.step` — the *ring alone*, not the merged geometry — has now gone too.
>
> **`tempcut_combined_holder.stl` is the whole of part 11's existence.** A revision to the merge
> starts from a mesh, not from CAD.
>
> **One hedge remains:** `thermalcut_sensorholder.3mf` is still in the folder (D-11 previously
> recorded it as deleted — it was not). As the Bambu project for the pre-merge workflow it carries the
> two halves' geometry, so it is the last thing standing between part 11 and mesh-only. **Do not
> delete it until a STEP or F3D of the combined part exists.**
>
> **Do this if the Fusion 360 design still exists in the cloud: re-export a STEP or F3D of the
> combined part.** If it does not, part 11 is mesh-only permanently — which matters because D-11
> already flags it as *superseded by design intent* (a simplified spacer absorbing parts 06 and 11),
> and that redesign would have to be modelled from scratch regardless.

### ✅ RESOLVED 2026-08-18 — the leads have an exit

The cutoff's two leads had no way out of the incubation module. Fixed at **part 09**, not here: its
floor was revised from two undersized slots to **3 × Ø5 mm holes**, the third specifically so the
cutoff can be **wired from inside the heat chamber** and dropped down into the circuit module at the
base. See [D-09](#d-09-heater-mount).

This settles the routing question for the consolidated spacer below: the wire exits do **not** have
to be designed into the spacer, because the leads leave through the floor of the part beneath it. The
consolidation is now purely about part count and sensor retention.

### ☐ Planned — consolidate 06 + 11 into one spacer

The intended fix is a **simplified spacer ring that holds the sensor and provides the wire exits**,
replacing both the plain spacer (part 06) and this ring. That would:

- **reduce the part count by one**, and
- **enable wire routing**, which the current pair does not solve at all.

Adjustability is what the split bought; the consolidated part has to preserve enough of it — either
by offering the sensor pocket at a chosen position per print, or by fixing the position once the
step-36 validation settles where it belongs. **Resolve step 36 before committing to the merged
design**, or the reprint-a-small-ring advantage is lost.

### ⛔ Print this part in PETG, not PLA — 2026-08-21

*(The slicer project that prompted this note has since been deleted. The requirement stands for
whatever project replaces it — it assigned both objects to **PLA**, slot 1, 220 °C / 55 °C bed.)*

**This part must not be PLA.** It sits inside the heater chamber holding the thermal cutoff, and
PLA's glass transition is **55–60 °C** — the KSD9700 is specified to trip at **55 °C**, so the ring is
expected to reach PLA's softening range *by design*, with no fault required. A ring that creeps or
sags moves the sensor, which changes the trip margin that
[step 36](../../spaceplacer_repo/projects/heater_v2/spaceplacer_heater_v2_howto.md) exists to validate.
This is the same PLA prohibition [D-01](#d-01-plate-holder) applies to the plate holder.

☐ **Slice this part in PETG.** Carry the requirement into the new project.

### ☐ Print settings — the deleted project deviated from this file's spec

Recorded so the same defaults do not come back:

| | That project used | This file specifies |
|---|---|---|
| Walls | **2** | **3+** |
| Infill | **15 %** | **20–30 %** |
| Layer height | 0.2 mm | 0.2 mm ✅ |
| Supports | off | as needed ✅ |

Thin walls and low infill on a **snap-fit** part are a specific risk: the snap features rely on wall
material to hold their spring. Either bring the project up to 3 walls / 20 % or record why this part
is an exception.

☐ **Leave enough lead length to reach the floor below.** The cutoff is now wired from inside the
chamber and its leads drop through part 09's floor, so the sensor's height in the spacer sets how much
slack the leads need. Moving the sensor up to satisfy step 36 lengthens that run.

## D-13 Light Spacer Lower Ring

`lightspacer_lower_ring.stl` — added 2026-08-24.

The light spacer carries the LED light ring in the **lamphouse position** of the Bogen enlarger the
device is built from. Without a stop it can slide down into the body; this ring is that stop.

### Geometry, measured from the mesh

Two Z levels (−94.07 and −66.68 in Fusion coordinates) and two radii (74.89 and 79.97 mm) — so the
part is a **plain extruded annulus**. There is no register lip, no taper, no lead-in chamfer, and no
fastener boss. Everything it does, it does by interference.

The **5.08 mm wall is exactly 0.200 in**, which suggests the ring was dimensioned in imperial against
the enlarger's own hardware rather than to the metric stack the printed parts otherwise use.

### ☐ The two numbers that matter are not recorded

Retention is a pure friction fit, so its behaviour is set entirely by clearances this file cannot
show:

| Interface | Ring dimension | Mating dimension | Status |
|---|---|---|---|
| Ring bore → light spacer OD | **149.78 mm** | ? | ☐ **not recorded** |
| Ring OD → enlarger body opening | **159.94 mm** | ? | ☐ **not recorded** |

The second is what makes it a *retaining* ring at all: the OD must exceed the body opening, or the
assembly passes straight through and the part does nothing. **Measure the enlarger body and record
it** — it is the one dimension that decides whether this design is correct, and it lives on a piece
of inherited hardware, not in CAD.
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

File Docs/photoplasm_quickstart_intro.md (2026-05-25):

# Photoplasm
### A light and pattern projector for biosensor-driven spatial imaging.

&nbsp;

**photo** (light) — the energy that drives the system.

**plasma** (formed living matter) — the substance of cells.

---

**Photoplasm** is a coined term that carries two simultaneous meanings. At the substrate level, it describes any light-responsive biological material — living cells or cell-free systems — that records a spatially patterned light exposure and produces a measurable output: fluorescence, pigment, enzymatic activity, or any biosensor-driven response. At the molecular level, it describes the light-responsive circuits within those systems: with any light-responsive synthetic biological platform, including those engineered specifically to calibrate and test the device in the most optimized and controlled manner. The instrument that delivers, patterns, and measures that light takes its name from both meanings.

---
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

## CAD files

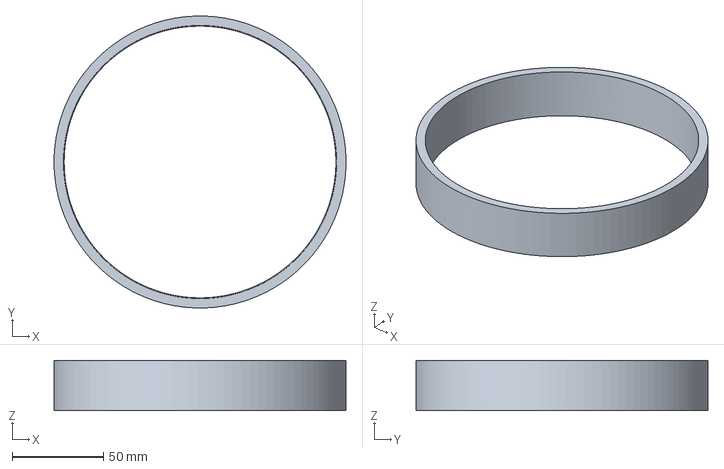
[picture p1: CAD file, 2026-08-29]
3D/lightspacer_lower_ring.3mf
159.9 x 159.9 x 27.4 mm

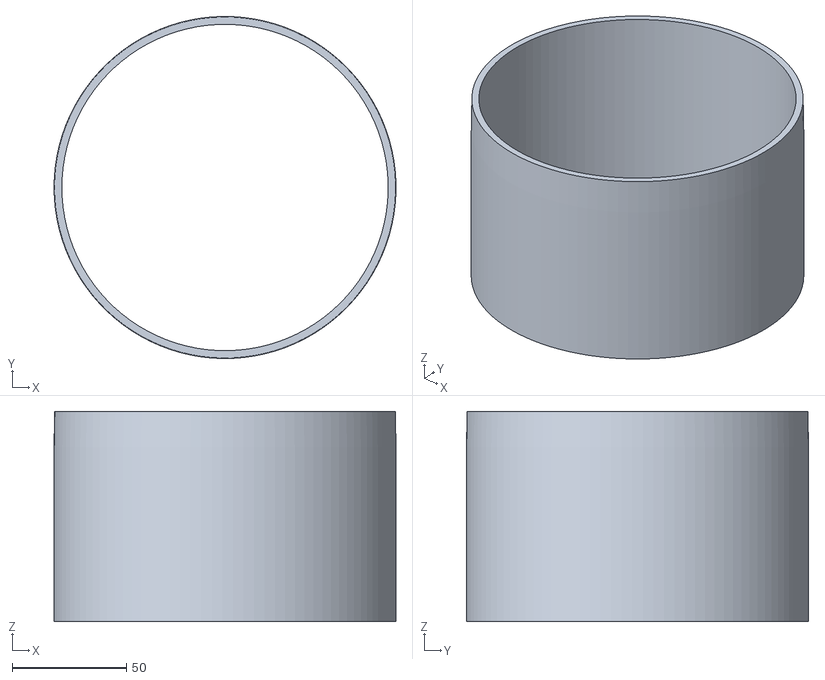
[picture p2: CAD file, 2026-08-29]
3D/lightspacer_large.stl
149.7 x 149.8 x 92.1

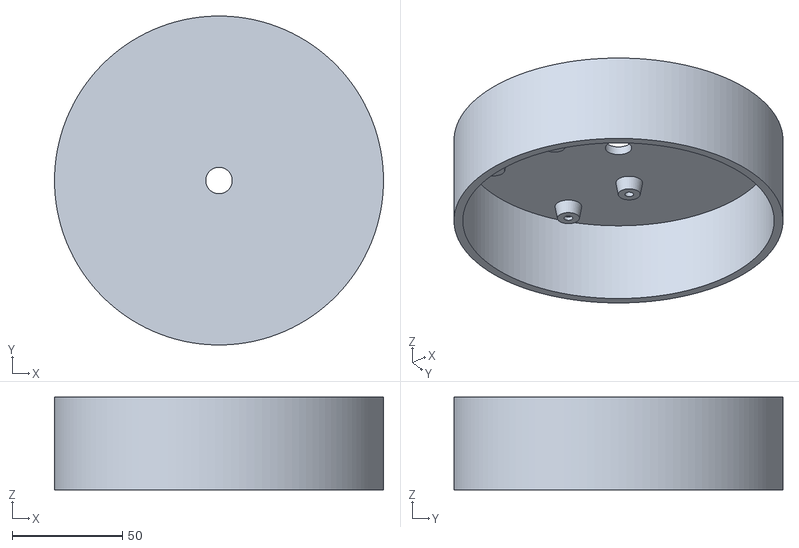
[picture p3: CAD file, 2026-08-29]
3D/light_circuit_hat.stl
149.2 x 149.2 x 42.1

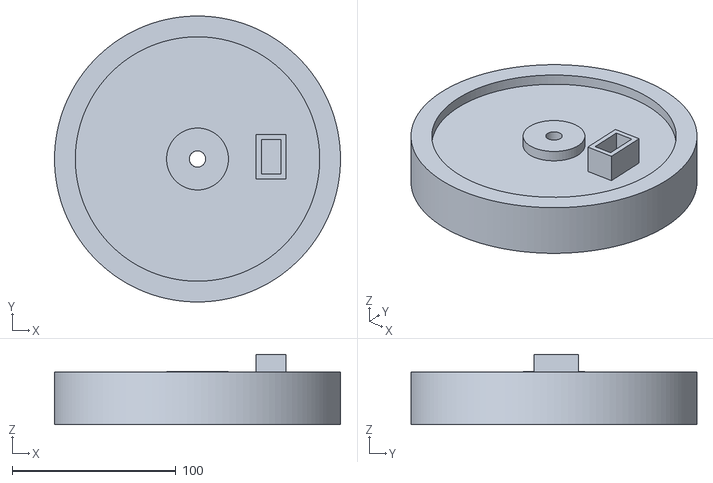
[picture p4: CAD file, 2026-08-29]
3D/Cree_lightring.stl
174.6 x 174.6 x 42.9

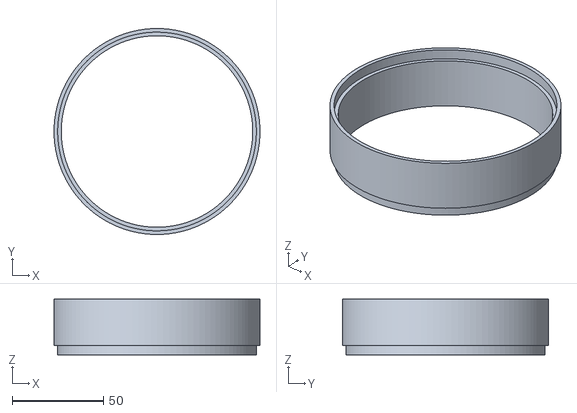
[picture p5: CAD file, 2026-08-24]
3D/HeaterSpacer.stl
113.1 x 113.1 x 30.5

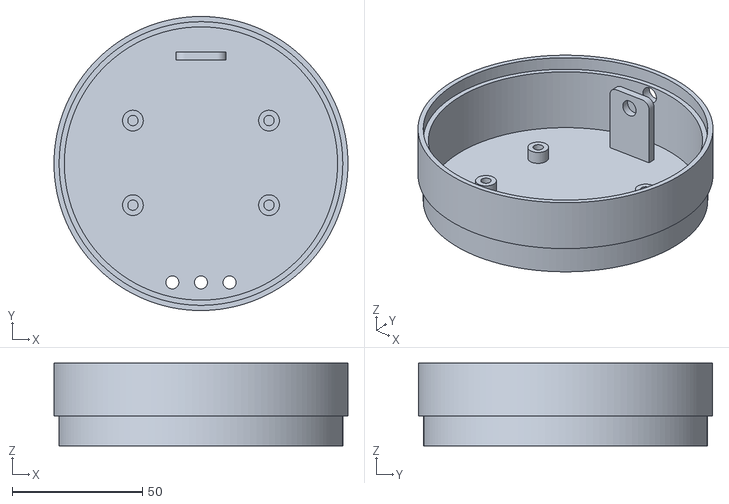
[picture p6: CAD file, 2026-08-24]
3D/my_heater_base_3holes.stl
113.0 x 113.0 x 31.8

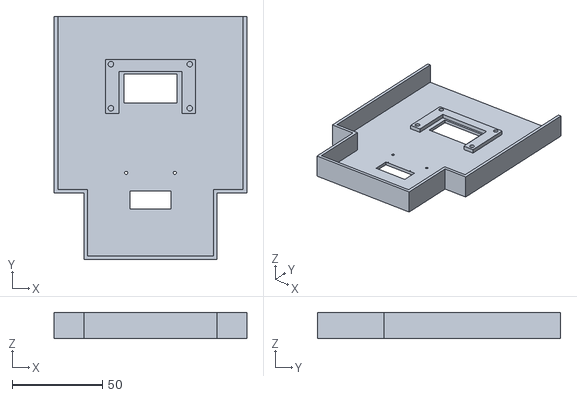
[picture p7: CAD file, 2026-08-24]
3D/LCD_Carrier_1.1_CF.stl
107.0 x 135.0 x 14.7

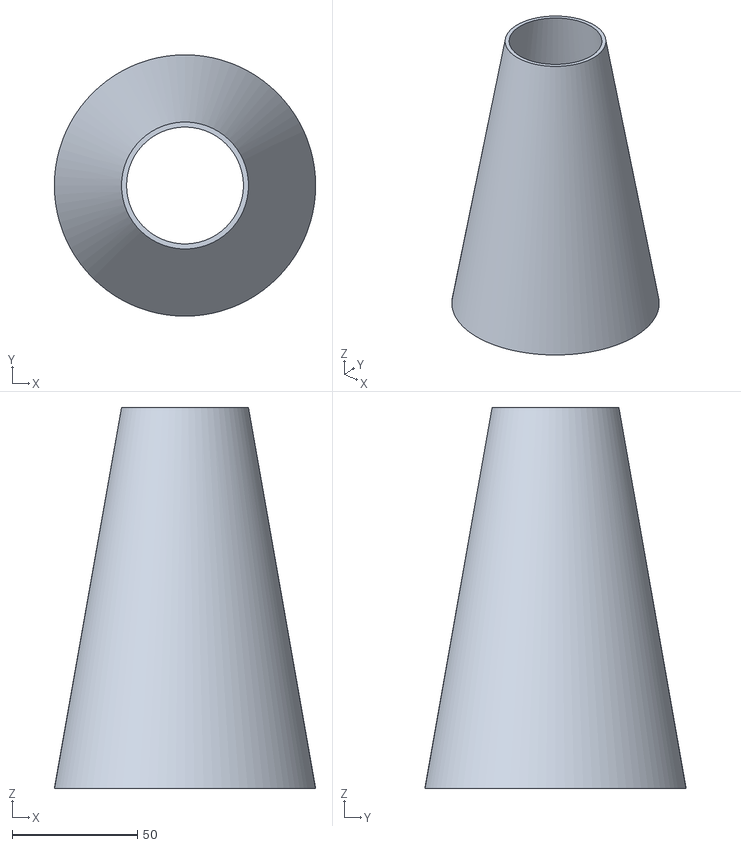
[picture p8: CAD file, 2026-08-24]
3D/Cone.stl
104.5 x 104.5 x 152.4

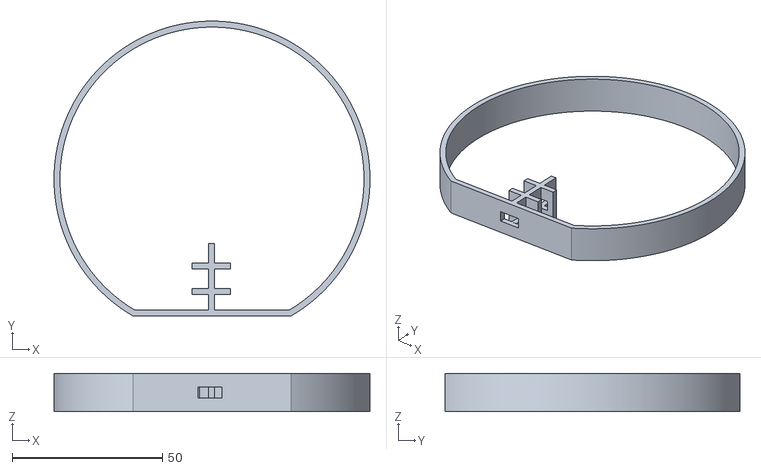
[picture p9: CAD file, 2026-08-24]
3D/tempcut_combined_holder.stl
105.0 x 98.0 x 12.7

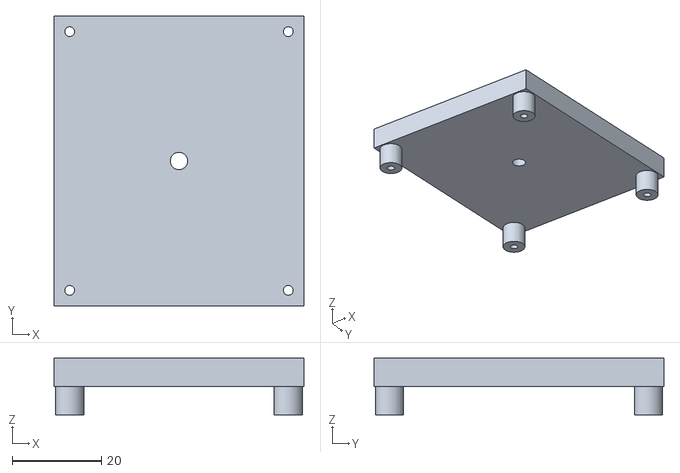
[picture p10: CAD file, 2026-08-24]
3D/pi5mount.stl
56.0 x 65.0 x 12.7

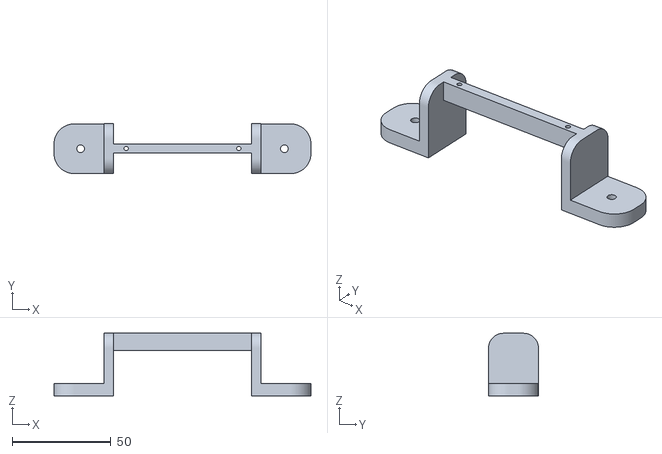
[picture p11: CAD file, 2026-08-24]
3D/gpio_breakout_mount.stl
130.4 x 25.4 x 31.8

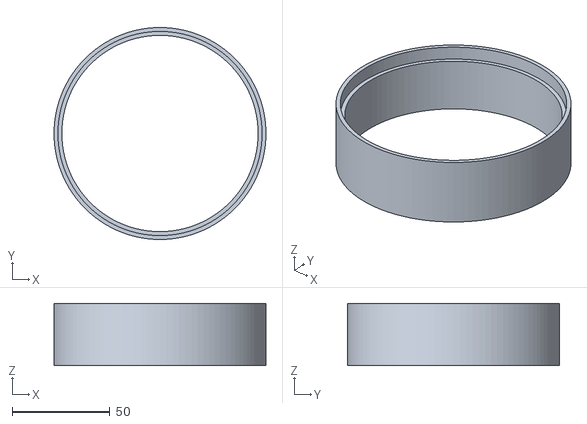
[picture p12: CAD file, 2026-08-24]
3D/Cone_Spacer_1in.stl
108.5 x 108.5 x 31.8

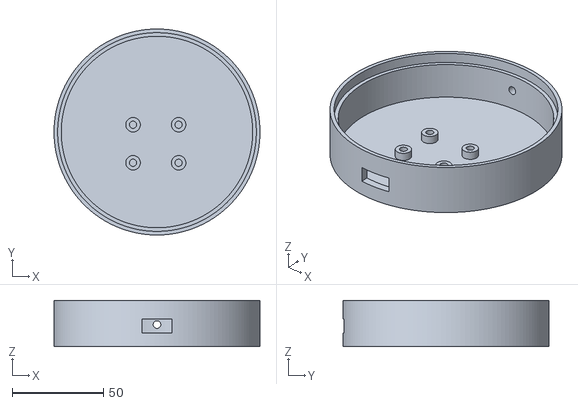
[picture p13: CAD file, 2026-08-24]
3D/Heater_DFR0457.stl
113.1 x 113.0 x 25.4

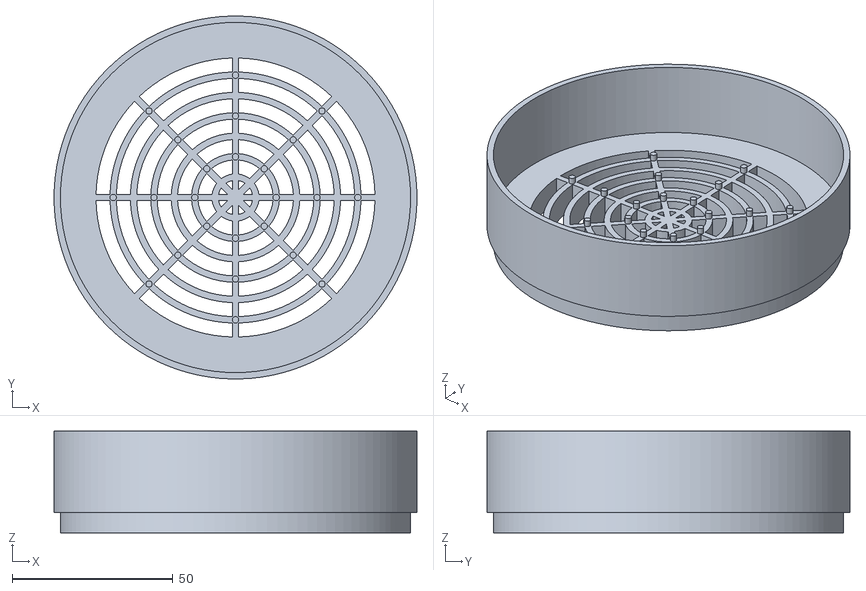
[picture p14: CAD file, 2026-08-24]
3D/Plate_Holder.stl
113.1 x 113.0 x 31.8

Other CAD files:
3D/lightspacer_lower_ring_draft.stl
3D/switchbox.stl
3D/thermalcut_sensorholder.3mf
3D/lower_stage_sensor.stl
3D/lightspacer_lower_ring.stl

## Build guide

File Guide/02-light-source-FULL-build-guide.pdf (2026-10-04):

# Light Source

## Build guide

BETA 1 . 0

© 2026 Eric Schneider · Beta 1.0 | edac8b1

## Before you start

Three rules. The first is the reason the others exist.

Cut the rail first — every time
The control board's off-state depends on the Pi's +5 V. If you unplug the Pi while the rail is live, the LEDs come ON. SW1 and the door interlock on the supply side are the only guarantee of darkness. Cut the rail before you touch anything.

Software off is not dark
A script that stopped is not a circuit that is open. After any run, cut SW1 or pull the supply.

Blue light: proxy on the bench, goggles otherwise
Bench work uses the white XP-E2 proxy. The 470 nm blue star runs only enclosed, with the interlock armed and OD6+ goggles on. 470 nm at close range damages vision without feeling bright enough to look away.

Nothing here is energised
This chapter is a tour. You are not asked to connect, power or touch anything — the safety rules arrive with the stage that needs them.

What you will be able to do
1. Identify every part of the light source on sight, and tell a purchased part from one you print.
2. Print the parts that are yours to print, in PETG, with the dimension on each that has to be right.
3. Explain why the emitter runs on a constant-current driver and what its CTRL pin does.
4. Assemble the lamphouse stack in the one order that works.
5. Prove a circuit on a breadboard before you solder it.
6. Transfer a proven circuit to perfboard: connectors, components, bridges, headers — in that order.
7. Wire a device into a machine, and dress the harness so a door can open through it.
8. Gate power with a switch and a door interlock, and prove both fail dark.
9. Bring the device up from a clean software install and read a result as pass or fail.

## What you need

Check this before a build session, not during one. A missing 18 AWG spool stops a session as surely as a missing driver.

Power

PSU15 — 15 V DC, ≥0.75 A, centre-positive barrel 15 V is a choice, not just a legal value. The driver runs on 13–24 V, but 24 V burns about 5 W as heat where 15 V burns about 2 W for the same light. Check polarity before it goes anywhere near the jack.

Purchased parts

Cree XP-E2 on a 20 mm star | The emitter. White proxy for bench work, blue 470 nm only enclosed.
Carclo 10140 — 20 mm wide diffuse optic | Spreads the emitter into an even field rather than a spot.
DLH-1UpEH aluminium housing | Carries the star and sinks its heat.
BuckPuck 3023-D-E-350 | Constant-current driver, 350 mA. Its CTRL pin is what the Pi drives.
NS-04 perfboard, 20 × 14 | The control board you will build.
1 kΩ · 100 Ω ½ W · 2N3904 | The board's three components.
WAGO 221-413 (3-way) · 221-2401 (2-way) | The LED ground star and the supply inlet splice.
SW1 guarded toggle · ME-8108 door interlock | The two gates. Neither is optional.
DC barrel jack + panel bushing | The inlet, and the breakaway point.
40-pin GPIO breakout and ribbon | Pi to breadboard and board.
Lamp rod — 1/8 IP threaded hollow, with nut and washer | Standard lamp-kit hardware. Mounts the light element to the ring, and the emitter leads run up its hollow centre.

Printed parts — PETG, all six

Light ring · circuit hat · large spacer · lower ring | The lamphouse stack.
Switch box · inlet bushing | The enclosure's printed furniture. An OEM electrical bushing or heat-shrink will stand in for the bushing.
PETG, not PLA — proximity to heat, not contact with it | The emitter and its heat sink run warm. PLA softens at a temperature the lamphouse reaches, and a spacer that creeps changes the optical distance — a dimension the exposure depends on.

Cabinet and door — NOT printed | Fabricated. Plywood for the first prototype, hinged to close light- tight; plexiglass, sheet metal, a modified cabinet or even cardboard are all legitimate later.

Wire and consumables

18 AWG stranded — power path | The gauge rule: 18 AWG power, 22 AWG logic, never below 24 AWG in a WAGO.
22 AWG stranded — logic and control | CTRL, GPIO and sense lines.
Dupont jumpers, M–F and F–F | Pi header and breadboard work.
Ferrules, heat-shrink, sleeving | Stranded wire into a WAGO wants a ferrule. Size printed pass- throughs for the SLEEVED outside diameter and deburr them.

Tools

Soldering iron, solder, flush cutters | The star is an aluminium board: it pulls heat away from the iron, so a joint that looks fine can be cold. Give it time to wet.

Wire strippers for 18–24 AWG

Multimeter with continuity | The only way to prove a rail is dead. “It looked right” is not a proof.
Helping hands | The star and the board are both awkward to hold.
OD6+ blue-light goggles | For any work with the 470 nm emitter.

## 02.0 The Path of Light

ONLINE: ACTIVITY 02.0 · 3D VISUALIZER

The device is one beam and a series of things done to it. Each step adds the next stage, in the order the light meets them.

The Whole Machine
Everything, assembled. A column of light with a living plate at the bottom of it: the source at the top, a lens to straighten the beam, a screen to put an image on it, a lens to project that image down, a dark chamber to carry it, and a warm stage to land it on. Every step after this one takes a stage away until only the source is left, then puts them back in the order the light meets them.

NOTE · Nothing here is energised. This chapter is a tour.

Fig 02.0-1 · 3D Visualizer ·

02.0.1

Light Source
Produce controllable, attenuable 470 nm light. This is where the photons start.

NOTE · Origin. Built in 02-light-source — Light Source.

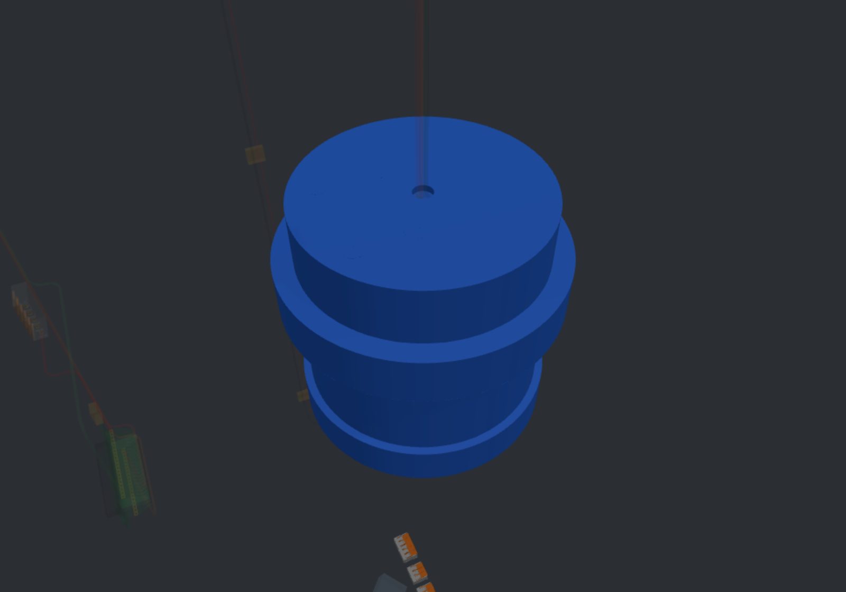
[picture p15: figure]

Fig 02.0-2 · 3D Visualizer ·

02.0.2

Condenser Lens
bogen-condenser
Turn a point-like emitter into an even, parallel field. Without this the projection is bright in the middle and dark at the edges, and the exposure is uncalibratable.

NOTE · Collimation. Built in 04-image-mask — Image Mask.

Fig 02.0-3 · 3D Visualizer · bogen-condenser

02.0.3

Image Mask
Impose the image on the beam. The mask sits in the enlarger's negative-carrier position and works subtractively, like a photographic negative.

NOTE · Modulation. Built in 04-image-mask — Image Mask.

Fig 02.0-4 · 3D Visualizer ·

02.0.4

Enlarger Lens
Project the mask onto the substrate, and provide the coarsest attenuation control the platform has. The f-stop is a (2.8/N)² term in the exposure model.

NOTE · Projection + attenuation. Built in 04-image-mask — Image Mask.

Fig 02.0-5 · 3D Visualizer ·

02.0.5

Cone and Spacers
Enclose the beam between lens and plate. The cone is the light-tight envelope of the optical path; the spacers set the throw in 1 in increments.

NOTE · Dark chamber. Built in 07-plate-stage — Plate Stage.

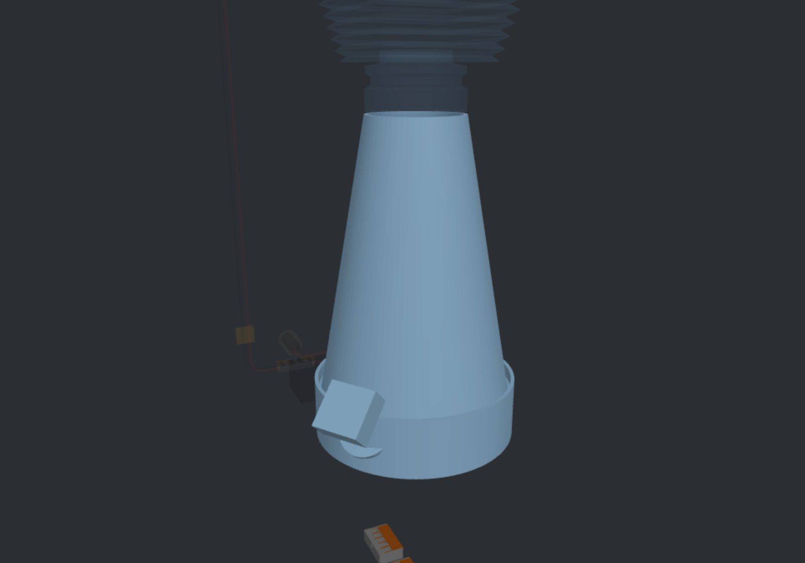
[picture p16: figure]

Fig 02.0-6 · 3D Visualizer ·

02.0.6

Plate Stage
Hold the substrate at the focal plane, with even airflow — and accept the spectral sensor in its place, at exactly the same height.

NOTE · The stage. Built in 07-plate-stage — Plate Stage.

Fig 02.0-7 · 3D Visualizer ·

02.0.7

Spectral Sensor
Measure what actually arrives at the substrate. Every irradiance number in the exposure model traces back to this sensor, mounted where the plate would be.

NOTE · Built in 07-plate-stage — Plate Stage.

Fig 02.0-8 · 3D Visualizer ·

02.0.8

Incubation Heater
Hold the substrate at 37 °C safely, for hours, with three independent hardware protections and a closed feedback loop.

NOTE · Documented in 10-incubation-heater; no chapter yet.

Fig 02.0-9 · 3D Visualizer ·

02.0.9

The Central Brain
The electrical layer under everything: the Pi, the GPIO breakout, the two shared stars, and the returns that must never bond to them.

NOTE · Documented in 11-circuit-and-power; no chapter yet.

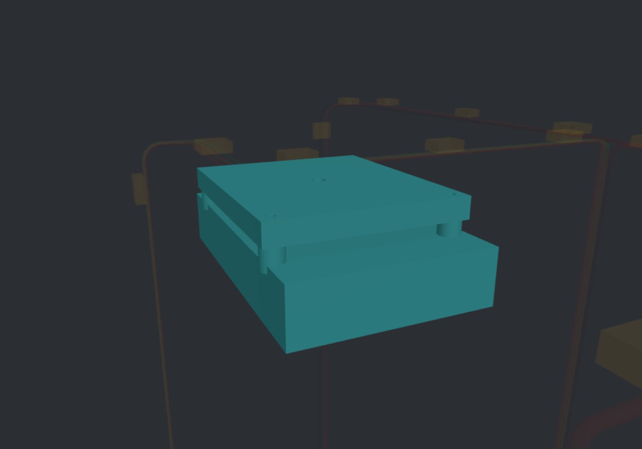
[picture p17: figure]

Fig 02.0-10 · 3D Visualizer ·

02.0.10

The Whole Machine, Again
Back where you started, and now every part of it has a name. The same cabinet, the same column — but you have seen what each stage is for, which ones the light passes through, which ones exist so that it can, and which chapter builds each of them.

NOTE · Next: 02 Light Source, where the photons start.

Fig 02.0-11 · 3D Visualizer ·

02.0.11

## 02.1 Parts, Tools and Consumables

ONLINE: ACTIVITY 02.1 · 3D VISUALIZER

Everything this chapter asks you to touch, laid out and recognised BEFORE a session starts. A missing driver found now costs a click; found at the bench it costs the evening. Nothing here is energised and nothing is wired -- this is identification.

The supply, and why 15V
psu15
A 15V DC brick, 0.75A or better, centre-positive barrel. The driver will run anywhere from 13 to 24V, so 15 is a choice rather than the only legal value: at 24V the driver burns about 5W as heat to make the same light 15V makes for about 2.

HAZARD · Check the polarity marking before the plug goes anywhere near the jack. Centre-positive is what this build expects.

Fig 02.1-1 · 3D Visualizer · psu15

02.1.1

The inlet, and the breakaway point
barrel-jack
A DC barrel jack and its panel bushing. The jack mounts inside the bushing, so the supply plug pushes in from outside and the cabinet never has to be opened to power the build.

NOTE · This is the deliberate breakaway: a tug on the supply lead is taken by the cabinet, not by the jack's solder tails.

Fig 02.1-2 · 3D Visualizer · barrel-jack

02.1.2

SW1, the first gate
sw1-light
A guarded toggle, panel legend LIGHT. It breaks the +15V rail upstream of everything else, which is the only reason any later step is safe to carry out.

HAZARD · The rail defaults ON. The BuckPuck's CTRL is inverted, so a Pi that is off or unplugged does not make the lamp dark -- SW1 does.

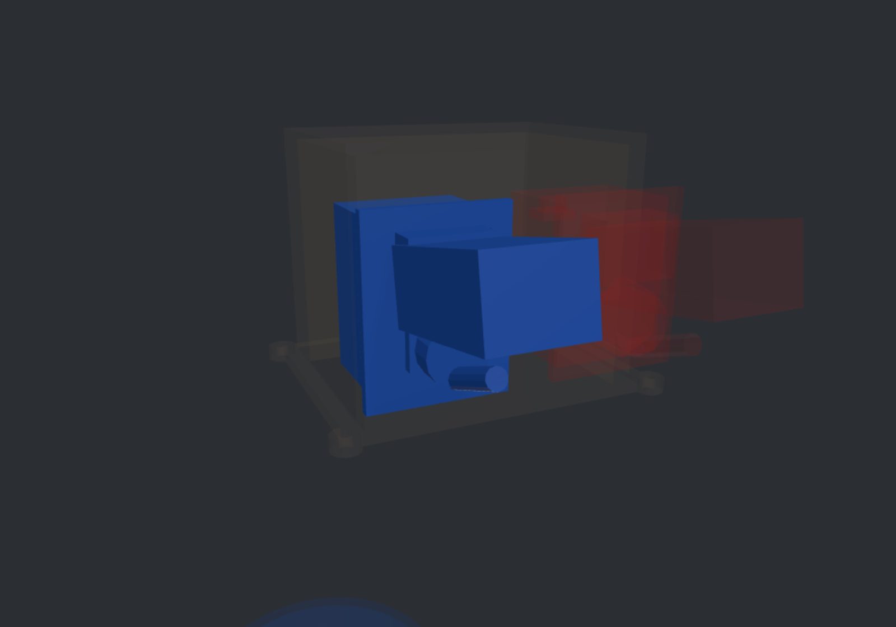
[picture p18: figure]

Fig 02.1-3 · 3D Visualizer · sw1-light

02.1.3

ILK1, the second gate
ilk1
An ME-8108 door interlock. Four terminals in two isolated pairs; only the NO pair, 3 and 4, is used, so the contacts close when the door is shut and open the rail the moment it is not.

HAZARD · Wired on 1 and 2 instead -- the NC pair -- it does the exact inverse and would pass any casual test. It is an electrical safety device, not a sensor.

Fig 02.1-4 · 3D Visualizer · ilk1

02.1.4

The emitter, in two versions
cree-xpe2-star
A Cree XP-E2 on a 20mm hex star. Two parts are used across the project, one at a time: a WHITE star for bench work, where the point is to watch the optics behave, and a BLUE 470nm star for calibration and exposure.

NOTE · Bring-up is done on the white proxy. The blue part is fitted once, at final integration, and only inside a shut enclosure.

Fig 02.1-5 · 3D Visualizer · cree-xpe2-star

02.1.5

The optic is a diffuser, not a collimator
carclo-optic
A Carclo 10140, 20mm wide diffuse. It spreads the emitter into an even field rather than narrowing it into a spot, which is the direction this column needs: the plate wants uniform illumination, and a collimated spot would expose the middle and starve the edges.

NOTE · Carclo make several 20mm optics that look alike in the hand. The 10140 is the wide DIFFUSE one --check the part number on the bag, not the shape.

Fig 02.1-6 · 3D Visualizer · carclo-optic

02.1.6

The housing is the heat sink
dlh-1upeh
A DLH-1UpEH aluminium housing. It carries the star and takes its heat away; the 20mm optic threads into the front of it.

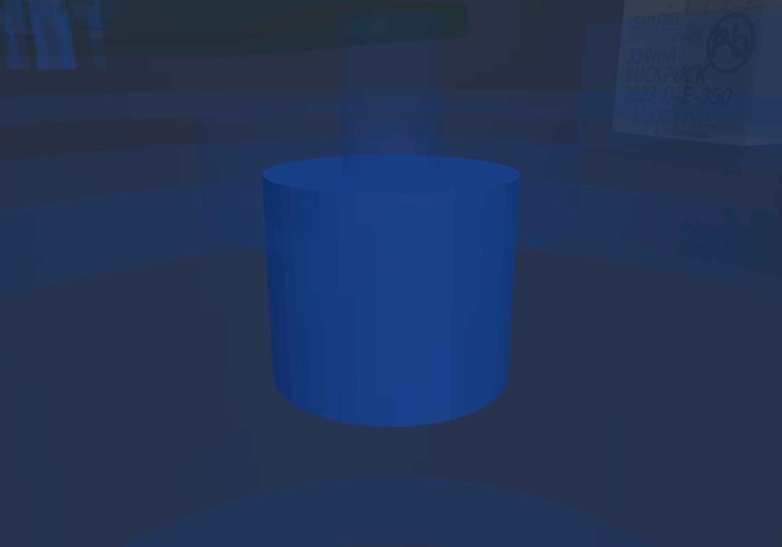
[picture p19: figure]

Fig 02.1-7 · 3D Visualizer · dlh-1upeh

02.1.7

The driver holds current, not voltage
buckpuck
A LuxDrive BuckPuck 3023-D-E-350: constant current at 350mA. Its CTRL pin is the one the Pi drives, and it is the only thing in the build that decides how hard the emitter runs.

Fig 02.1-8 · 3D Visualizer · buckpuck

02.1.8

The board, and its three components
ns04-perfboard
An NS-04 perfboard, 20 × 14. Onto it go exactly three parts: a 1 kΩ resistor, a 100Ω ½W resistor and a 2N3904 transistor. One sets how hard the transistor is driven; the other limits what flows through it.

NOTE · Perfboard holes are M2. Standoffs that carry this board are M2 as well, not the M3 the rest of the build defaults to.

Fig 02.1-9 · 3D Visualizer · ns04-perfboard

02.1.9

The connectors that make the joins
wago-led-gnd
WAGO 221-413 for the LED ground star and 221-2401 for the supply inlet splice. Stranded wire into a WAGO wants a ferrule.

NOTE · The gauge rule for this chapter: 18 AWG on the power path, 22 AWG for logic and control, and never below 24 AWG into a WAGO.

Fig 02.1-10 · 3D Visualizer · wago-led-gnd

02.1.10

The breakout, and the mistake it invites
gpio-bridge
A 40-pin GPIO breakout and its ribbon, which is how the Pi reaches the breadboard and the board.

HAZARD · Check the ribbon is not 180° reversed before anything is harnessed to it. A flipped ribbon gives a pinout that looks entirely plausible and is wrong end to end -- it has already cost one full false bring-up here.

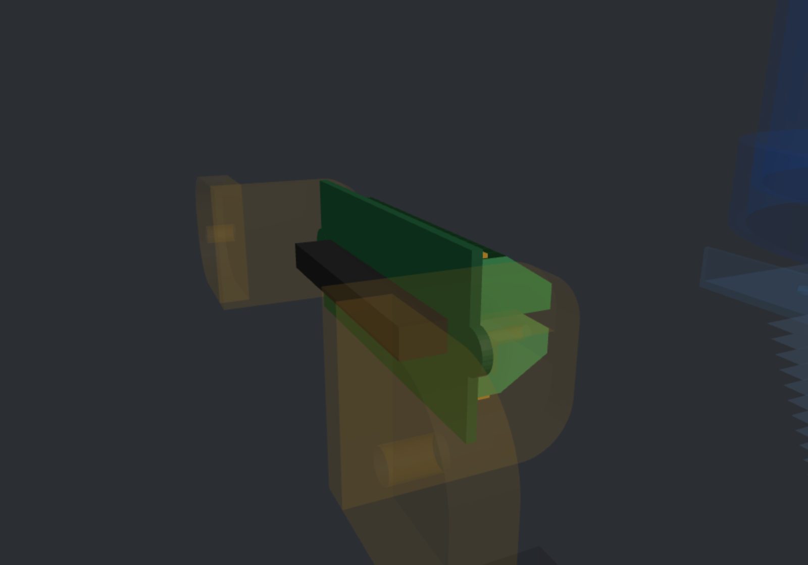
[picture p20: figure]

Fig 02.1-11 · 3D Visualizer · gpio-bridge

02.1.11

## 02.2 Printed Parts

ONLINE: ACTIVITY 02.2 · 3D VISUALIZER

Six parts you print, and two you do not. Each one is identified by the job it does and by the dimension or feature that has to be right for it to do that job. PETG for all six: the emitter and its housing run warm, PLA softens at a temperature the lamphouse reaches, and a spacer that creeps changes an optical distance the exposure depends on.

Light ring -- seats the star on axis
cree-lightring
Holds the single emitter star on the optical axis and on a known plane, so the die sits where the diffuser and the column below expect it.

NOTE · A circular ring with one centred LED. The ring is the carrier; the single star sits at its centre, on the axis the whole column is measured from.

Fig 02.2-1 · 3D Visualizer · cree-lightring

02.2.1

Spacer seat -- the 1° draft is the part
lightspacer-lower-ring
Seats the spacer stack. The 1° draft is what holds it: a seat with a draft angle grips the stack above it, where a flat one lets it slip.

NOTE · Check the fit before you print a stack of them: the seat's outer diameter has to land ON the enlarger body opening, not drop through it.

Fig 02.2-2 · 3D Visualizer · lightspacer-lower-ring

02.2.2

Light spacer -- sets the drop
lightspacer-large
Sets the distance from the emitter to the optics below. That is an OPTICAL dimension, not a mechanical one: its height is part of the exposure, so print it in PETG and print it accurately. A spacer that creeps moves the light.

NOTE · Print it in gray matte PETG. Inside a 470nm lamphouse the inner surface is working: anything it bounces back up the column is stray light in the image.

Fig 02.2-3 · 3D Visualizer · lightspacer-large

02.2.3

Circuit lid -- closes the lamphouse, carries the board
light-circuit-hat
Closes the top of the lamphouse and gives the NS-04 board its four standoffs. The four Ø4.0 bores run through the top face and are closed by the hardware that goes into them: bolting the perfboard down fills each one, so the lid is dark once the board is on it.

NOTE · Perfboard holes are M2, so the standoffs and bolts here are M2 -- not the M3 the rest of the build defaults to. Fit the board before you trust the box to be dark.

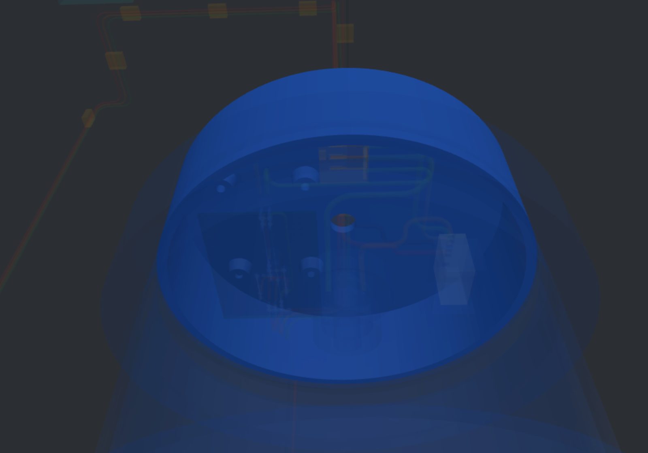
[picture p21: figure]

Fig 02.2-4 · 3D Visualizer · light-circuit-hat

02.2.4

Switch panel -- both rail switches, outside the lid
switchbox
Carries both rail switches on the outside of the lid, where a hand reaches them with the door shut. That is the whole point of it: the gates must be usable without opening the thing they make safe.

NOTE · Size the two switch holes Ø12.5mm for the KN3C-101AA. It carries SW1 (LIGHT, +15V, with ILK1) and SW2 (HEAT, +12V, with the fuse and the KSD9700) -- two switches on two separate rails, in one panel.

Fig 02.2-5 · 3D Visualizer · switchbox

02.2.5

Inlet bushing -- three ways to have one
cable-retainer
Fills the hole in the back wall and holds the barrel jack in it, so a pull on the supply lead is taken by the cabinet rather than by the jack's solder tails. An OEM electrical bushing sized to the hole does this job and is the quickest route: it is a standard part, it is cheap, and it is already designed.

HAZARD · CHALLENGE -- design it yourself. This is the smallest real part in the build and the best one to learn on: a bore to suit the jack body, a shoulder that lands on the wall, and some way of retaining it -- a nut, a snap, or printed-in threads. One feature at a time, each one testable by whether the jack sits square and the lead cannot be pulled out.

NOTE · RAPID ROUTE -- heat-shrink tubing. Shrunk over the lead where it passes the wall it gives you strain relief and a light seal in one, with no printing and no waiting. Good enough to prototype the whole inlet and find out where the hole should actually be.

Fig 02.2-6 · 3D Visualizer · cable-retainer

02.2.6

The cabinet is made, not printed
enclosure-shell
The shell is fabricated rather than 3D printed. The first prototype is plywood throughout, which makes it easy to mount and position every component and to move one when it turns out to be in the wrong place. Later iterations have room to be cut and assembled opaque plexiglass, or a sheet-metal fabrication; an existing structural cabinet can be modified instead, and a cardboard box is a perfectly honest enclosure for an early iteration.

NOTE · The floor is the datum. Every position in this build is measured from it, so whatever you make the cabinet from, build it to the interior dimensions first and place the parts into it -- not the other way round.

Fig 02.2-7 · 3D Visualizer · enclosure-shell

02.2.7

The door, and the seal that makes it dark
enclosure-door
Also fabricated, in plywood for the first prototype. What matters is the hinging: the door and the shell have to close to a light-tight seal, so the hinges are set to pull the door flat against the opening rather than merely hold it there.

HAZARD · The door carries ILK1. Opening it must CUT the 470nm rail -- not be noticed by software, not be logged. That is an electrical requirement on the door, and it is why the interlock sits under the ceiling with its roller facing this panel.

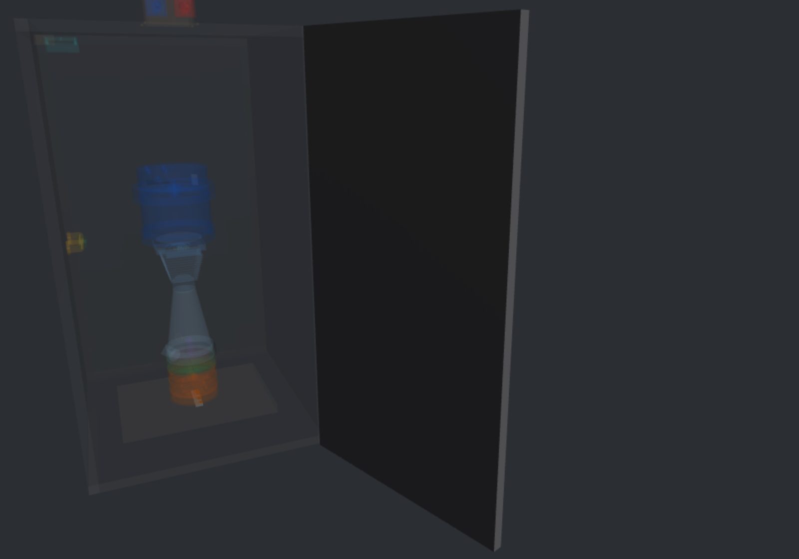
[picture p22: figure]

Fig 02.2-8 · 3D Visualizer · enclosure-door

02.2.8

## 02.3 Door Switch and Power Cutoff

ONLINE: ACTIVITY 02.3 · 3D VISUALIZER

SW1 on the supply side and the door interlock. The rail defaults ON, so these two are the only things that make it dark — everything after this section assumes you have used them.

Cut the rail before anything else
sw1-light
Open SW1 (panel legend LIGHT), shut the Pi down, then unplug the supply brick. Do it in that order.

HAZARD · The BuckPuck's CTRL is INVERTED: with nothing driving it, the rail is ON. A Pi that is off does not make the lamp dark — SW1 and the door interlock are the only things that do.

Fig 02.3-1 · 3D Visualizer · sw1-light

02.3.1

Find the second gate
ilk1
Locate the ME-8108 door interlock on the inside top of the enclosure, just under the ceiling, with its roller facing the door. Shutting the door presses that roller and engages the switch. Check that it is wired on terminals 3 and 4 — the NO pair — so the contacts close only while the door is shut.

HAZARD · Wired on 1 and 2 instead, the NC pair, it does the exact inverse: dark when open, live when closed. It would pass any casual test.

Fig 02.3-2 · 3D Visualizer · ilk1

02.3.2

## 02.4 The Light Element and Its Driver

ONLINE: ACTIVITY 02.4 · 3D VISUALIZER

What makes the light, what shapes it, and what holds it at 350 mA. No tools and nothing energised -- this is the activity where you learn what you are about to wire.

Find the emitter and its board
cree-xpe2-star
Identify the 20mm hex metal-core board with a single Cree XP-E2 on it. The board spreads the die's heat into the aluminium housing and gives the emitter something to be wired and mounted by.

NOTE · Two stars are used across the project, one at a time: a WHITE part for bring-up, where the point is to see the optics work, and a BLUE 470nm part for calibration and exposure.

Fig 02.4-1 · 3D Visualizer · cree-xpe2-star

02.4.1

The die is the source
cree-xpe2-emitter
The 3.5mm die sits ON the star's metal board rather than in place of it. One die, not an array.

NOTE · The wavelength is what the biology responds to, so the white part proves the light path and the blue part is the instrument.

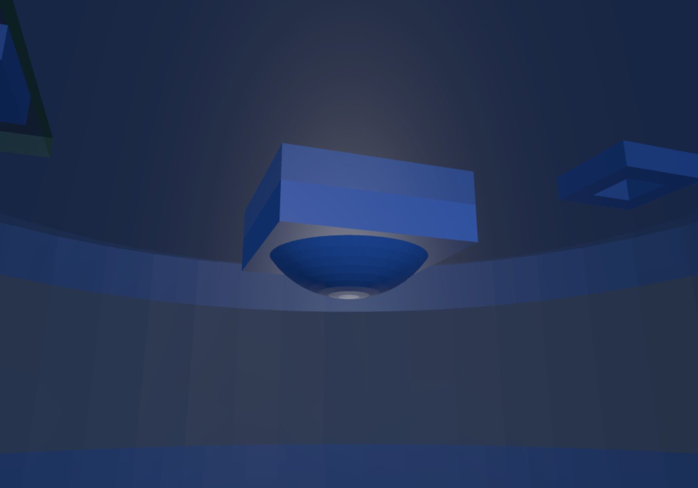
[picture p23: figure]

Fig 02.4-2 · 3D Visualizer · cree-xpe2-emitter

02.4.2

The housing is the heat sink
dlh-1upeh
Identify the DLH-1UpEH aluminium housing. The 20mm optic threads into its front and the 20mm star seats behind it, so unscrewing the housing is how you reach the die.

NOTE · It does two jobs at once: holding the star and the lens in register, and carrying heat out of a 350mA emitter. That is why it is aluminium and not printed.

Fig 02.4-3 · 3D Visualizer · dlh-1upeh

02.4.3

The optic spreads, it does not focus
carclo-optic
Identify the Carclo 20mm optic. It is WIDE DIFFUSE, not a collimator: it spreads the emitter's output into an even field rather than narrowing it into a beam.

NOTE · The plate wants uniform illumination across its whole area. A collimated spot would expose the middle and starve the edges.

Fig 02.4-4 · 3D Visualizer · carclo-optic

02.4.4

The ring seats the star on axis
cree-lightring
Identify the printed carrier that holds the star on the optical axis and on a known plane, so the die sits where the diffuser and the column expect it.

NOTE · A circular ring with one centred LED — the ring carries, the single star sits at its centre.

Fig 02.4-5 · 3D Visualizer · cree-lightring

02.4.5

The driver holds the current, not the voltage
buckpuck
Identify the LuxDrive BuckPuck 3023-D-E-350. It holds the emitter at 350mA whatever the supply does, which is what makes an exposure repeatable. A resistor and a fixed supply would not: the same circuit would give a different brightness at 15V than at 24V.

HAZARD · Its CTRL input is INVERTED. With nothing driving CTRL the rail defaults ON — which is why the switch and the door interlock, not software, are what make the device dark.

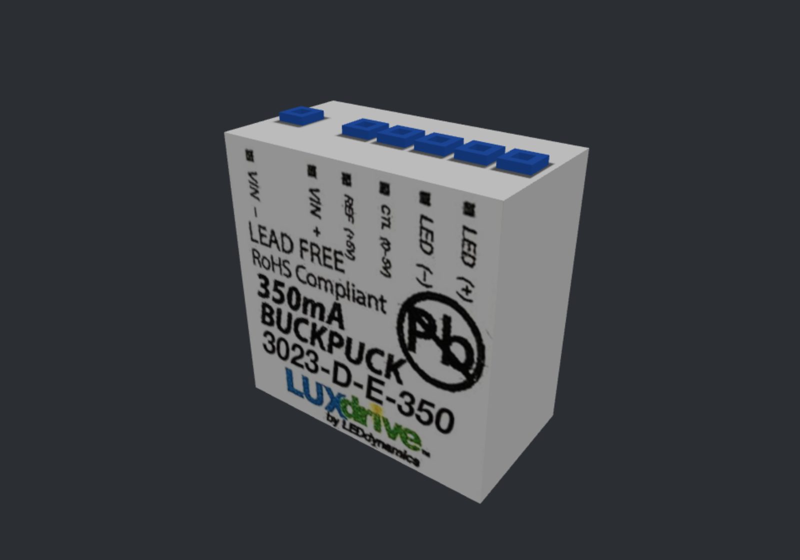
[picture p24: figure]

Fig 02.4-6 · 3D Visualizer · buckpuck

02.4.6

Know its four leads before you wire them
buckpuck
The driver has four: Vin+ and Vin− to the gated supply, LED+ to the star's anode, and LED− to the ground star. A fifth, CTRL, is the grey lead the board drives.

NOTE · You will land every one of these in activity 02.8 and 02.9. Reading them now is what makes those steps short.

Fig 02.4-7 · 3D Visualizer · buckpuck

02.4.7

## 02.5 Breadboard the Circuit

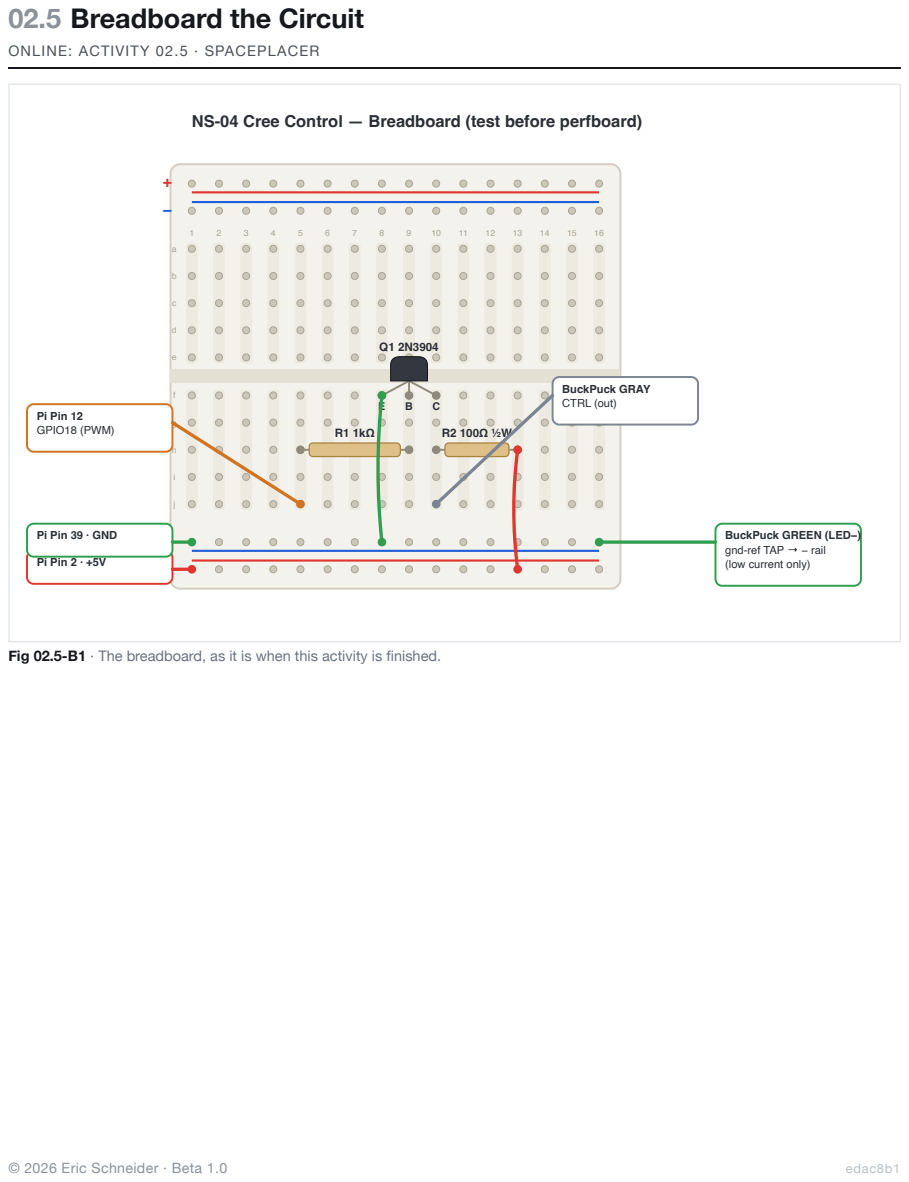
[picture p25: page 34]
Pi Pin 12 GPIO18 (PWM); Pi Pin 2 · +5V; BuckPuck GRAY CTRL (out)

ONLINE: ACTIVITY 02.5 · SPACEPLACER

NS-04 Cree Control — Breadboard (test before perfboard)

Pi Pin 39 · GND

BuckPuck GREEN (LED−)
gnd-ref TAP → − rail
(low current only)

Fig 02.5-B1 · The breadboard, as it is when this activity is finished.

None of this touches the breadboard. The driver makes the current; the emitter uses it; the loop closes at a WAGO.

the LED’s metal-core board — NOT the ground star

### 0 V ground star — WAGO 221-413, three ways

thin green tap → breadboard − rail · Pi Pin 39

a reference, not a return: it carries almost no current

Fig 02.5-B2 · The off-board loop. It is NOT on the breadboard: the rails stay isolated.
Two things can be wrong before you start, and both look fine: the breakout can be on backwards, and the board can be read off by one column.

Q1 is the only part with an orientation. Get it wrong and the circuit does nothing, or conducts when it should not.

Find the five columns you will use
Locate columns 5, 8, 9, 10 and 13. Every part of this circuit lands on one of them: 5 is the GPIO input, 8·9·10 are the transistor's emitter, base and collector, and 13 is the +5 V tap. Nothing goes anywhere else.

NOTE · Within a column, the five tie points a–e are one node and f–j are another. The centre groove separates them — that is what lets a chip straddle it.

02.5.1

Meter the breakout before you trust its labels
pi-p12
With the Pi ON and the breadboard not yet connected, meter the breakout's pads against the Pi's own ground: the 5V pad should read +5 V, the GND pad 0 V, and the GPIO18 pad +3.3 V once you set it high. Confirm all three before continuing.

HAZARD · A ribbon fitted 180° out mirrors all 40 pins. Every voltage reads backwards and +5 V arrives on GPIO18 — a 3.3 V input. A full bring-up has already been lost to this once, and nothing about the assembled cable looks wrong.

02.5.2

One sets how hard the transistor is driven; the other limits what flows through it. They are not interchangeable, and one of them has a wattage requirement.

Two wires connect the circuit you have built to the two power rails running down the edges of the board.

Seat Q1 across columns 8, 9 and 10
Q1
Hold the 2N3904 with its FLAT face toward you and its legs down, then push it into row f so the legs land in columns 8, 9 and 10. Press until the shoulders of the legs meet the board.

NOTE · Flat face toward you puts the pins in the order emitter · base · collector, left to right. Turned around, the same three legs read collector · base · emitter and the circuit is backwards.

02.5.3

Confirm E · B · C, left to right
Check the three legs against the board: 8 is the emitter, 9 the base, 10 the collector. Say it out loud once — the next four steps are written in those terms and never in column numbers alone.

02.5.4

Fit R1, 1 kΩ, from column 5 to the base
R1
Bend the legs of the 1 kΩ resistor and seat it in row h, from column 5 to column 9. This is the only path from the Pi's GPIO pin into the transistor's base, and it is what keeps the Pi from sourcing more current than it can.

NOTE · Row h is in the same column-node as row f, so landing on 9h connects it to Q1's base leg at 9f. You do not need a jumper between them.

02.5.5

Fit R2, 100 Ω, from the collector to column 13
R2
Seat the 100 Ω resistor in row h, from column 10 to column 13. It is the pull-up on CTRL: with Q1 off it lifts the collector to about 4.6 V, which is what holds the driver OFF.

HAZARD · R2 must be a ½ W part. It dissipates about 230 mW with the rail on — a ¼ W resistor runs at its limit and is acceptable only for a brief bench test, never in the assembled device.

02.5.6

Jumper the emitter to the − rail
8f-8Bm
Run a jumper from 8f down to the − rail. This gives the emitter its return path. Use the − rail nearest you and push both ends fully in.

NOTE · Loose legs are the most common breadboard fault and the hardest to find: the circuit works, then stops when the bench is bumped.

02.5.7

Jumper column 13 to the + rail
13h-13Bp
Run a jumper from 13h up to the + rail. R2's high side now has +5 V waiting for it, and the circuit is complete except for what comes in from outside.

02.5.8

The circuit is now built and NOT yet connected to the Pi. This is the only moment at which the next test is possible, and it is the reason you breadboard at all.

Power first, ground second, signal last. That order means the signal pin never arrives at a circuit whose reference is still floating.

Two thin wires go to the BuckPuck. The 350 mA that actually lights the emitter does not come near this breadboard.

Column 5 must read OPEN to the − rail
5
With the Pi off and nothing plugged into the breadboard, set your meter to resistance and measure from column 5 to the − rail. It must read OPEN — no continuity. If it does not, find the short before you go on.

02.5.9

Column 5 must read OPEN to the + rail
5
Measure from column 5 to the + rail. This must also read OPEN.

HAZARD · Column 5 is where the Pi's GPIO18 lands, and GPIO18 is a 3.3 V input. If column 5 is connected to the + rail — a jumper one column off, a leg touching — then landing Pin 12 puts +5 V straight into it. Pass both measurements before you connect anything to the Pi.

02.5.10

Pi Pin 2 (+5 V) to the + rail
pi-p2
Run the RED lead from Pi Pin 2 to the + rail at the left end of the board.

02.5.11

Pi Pin 39 (GND) to the − rail
pi-p39
Run the BLACK lead from Pi Pin 39 to the − rail at the left end. The Pi and the circuit now share a reference — without this the circuit cannot switch.

02.5.12

Pi Pin 12 (GPIO18) to column 5
pi-p12
Only now, with both gate measurements passed, run the ORANGE lead from Pi Pin 12 into column 5 — the free end of R1.

NOTE · GPIO18 is the hardware-PWM pin. Later, when the software dims the lamp, this is the wire the duty cycle travels down.

02.5.13

The collector out to the BuckPuck's CTRL
bp-ctrl
Run the GRAY lead from column 10 — the collector — to the BuckPuck's CTRL input. This is the circuit's one output.

HAZARD · CTRL is INVERTED: pulling it LOW runs the driver at full output, and R2 holds it near +5 V to keep the rail OFF. That off-state needs the Pi’s +5 V — if the Pi loses power while +15 V is live, CTRL falls and the
lamp comes ON.

02.5.14

The circuit is built and the driver is landed. Now close the loop that actually carries the current, off the board, on the WHITE emitter.

The driver's LED− reference to the − rail
bp-ledm
Run the GREEN lead from the BuckPuck's LED− to the − rail at the right-hand end of the board. Land it at ONE point only.

NOTE · This is a reference tap, not a return path: it carries almost no current. Its job is to let the transistor and the driver agree on what 0 V means.

02.5.15

Know what is not on this board
Trace the 350 mA loop once: BuckPuck LED＋ goes straight to the star’s anode, and the star’s cathode returns straight to LED−. The only two wires joining the two circuits are the GRAY CTRL wire and the thin green reference tap — both low current.

NOTE · The word "star" is used for two different things. The Cree star is the LED’s metal-core board. The ground star is a WAGO junction. They are not the same node — the LED star only references the ground star through the thin green tap.

02.5.16

Fit the WHITE XP-E2 star, not the blue one
cree-xpe2-star
Mount the white XP-E2 star. Every bring-up in this chapter is done on white; the 470 nm blue star goes in once, at final integration, after the enclosure is closed and the interlock is proven to fail dark.

NOTE · The two stars are physically identical, so nothing about the board will stop you fitting the wrong one. Check the part before it goes in.

02.5.17

LED＋ from the driver to the star’s anode
ledp
Run the ORANGE LED＋ lead from the BuckPuck to the star’s anode. This leg carries the full 350 mA and never comes near the breadboard.

02.5.18

Close the return through the ground star
cathode
Run the star’s cathode into the 3-way WAGO, and the BuckPuck’s LED− into the same WAGO. That junction is the one point where the 350 mA return and the board’s reference tap meet.

NOTE · Three conductors land there: the star’s cathode, the driver’s LED−, and the thin green tap you ran to the − rail. One splice, one point.

02.5.19

Gate the ＋15 V before you connect it
vin
Run the supply into the BuckPuck’s Vin＋ through SW1, and through the door interlock if the enclosure is built. Open SW1 before you plug the brick in.

HAZARD · SW1 and the interlock are the only things that guarantee darkness. The driver’s CTRL is inverted and its off-state depends on the Pi’s ＋5 V, so cutting the rail is the only cut that does not depend on software.

02.5.20

The whole circuit, on and off the board, proving itself — and the power order that keeps it from lighting when you did not ask it to.

Power the Pi FIRST, then close SW1
Boot the Pi and let it settle, then close SW1. In that order.

NOTE · This is the single most important habit in the chapter, and it is the one a bench test teaches you badly if you get away with the wrong order once.

02.5.21

Drive GPIO18 high — the white emitter lights
Run pinctrl set 18 op dh. Q1 saturates, CTRL falls to about 0.2 V, the BuckPuck runs, and the white star lights at 350 mA. If it does not, open SW1 before you start looking.

NOTE · GPIO18 HIGH is the lamp ON. Two inversions cancel — the Pi’s high turns Q1 on, and the driver runs at full output when CTRL is pulled low.

02.5.22

Drive GPIO18 low — it must go out
Run pinctrl set 18 op dl. Q1 turns off, R2 lifts CTRL to about 4.6 V, and the emitter goes dark. Both halves must pass before this circuit goes anywhere near copper.

NOTE · That is the whole point of breadboarding it: you have just proven the exact circuit you are about to solder, on the exact emitter, with nothing committed.

02.5.23

Prove it fails dark
With GPIO18 still high and the emitter lit, open SW1. It must go out and stay out. If the enclosure and its interlock are built, open the door with SW1 closed and confirm the same.

HAZARD · A lamp that only goes out when the software says so is not gated. The rail cut is the proof, and it is the one you repeat every time before you put your hands in.

NOTE · Then power down in order: SW1 open first, Pi second.

02.5.24

## 02.6 Build the NS-04 Board

ONLINE: ACTIVITY 02.6 · 3D VISUALIZER

Three components, two headers and five jumpers, in the order that keeps the board flat on the bench — lowest first. Do all of it before the board goes near the machine.

Orient the board
ns04-perfboard
Set the board down with the IN header at column A and the OUT header at column T, rows running 1–14. Get this the right way round before you start: every instruction below names a pad by column and row.

Fig 02.6-1 · 3D Visualizer · ns04-perfboard

02.6.1

Solder R1, 1 kΩ, into E6 and I6
ns04-r1
Form the 1 kΩ resistor’s legs to 12 mm and drop them into E6 and I6, in row 6. Lay it flat on the board, solder from the back, then trim the legs flush.

NOTE · Resistors first, because they lie flattest. A board with nothing tall on it sits face-down on the bench while you solder, and every leg stays where you put it.

Fig 02.6-2 · 3D Visualizer · ns04-r1

02.6.2

Solder R2, 100 Ω, into F10 and J10
ns04-r2
Form the 100 Ω resistor the same way and fit it into F10 and J10, in row 10.

HAZARD · R2 must be a ½ W part — it is visibly fatter than R1, about 8.5 mm long against 6.3. It dissipates ~230 mW whenever Q1 is conducting. A ¼ W resistor fits the same holes and runs at its limit.

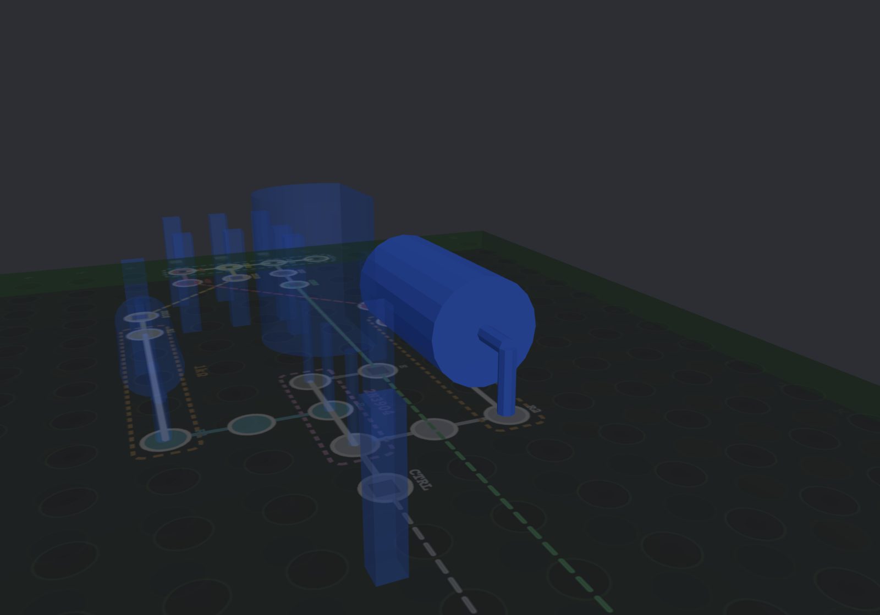
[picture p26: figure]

Fig 02.6-3 · 3D Visualizer · ns04-r2

02.6.3

Solder Q1, the 2N3904, into H8, I8 and J8
ns04-q1
Fit the transistor with its FLAT face toward the board’s row-14 edge, legs into H8, I8 and J8. Stand it about 3 mm off the board so the legs can be cleaned up, and solder the middle leg first.

HAZARD · Orientation is the whole step. H8 is the emitter, I8 the base, J8 the collector — which is what you get with the flat facing that way. Turned round, the same three legs read collector, base, emitter, and the circuit conducts when it should not.

NOTE · Solder one leg, check the body is square and seated, then do the other two. Reheating one joint to straighten it is easy; reheating three is not.

Fig 02.6-4 · 3D Visualizer · ns04-q1

02.6.4

Solder the ten male header pins
ns04-perfboard
Fit a male header pin into each of B7, D6, B8, E10, B9, H9, C9, S9, K8 and S8 — the two ends of each of the five jumpers — and solder each one into its own pad. They are not connected to anything yet; that comes next.

NOTE · The pins do two jobs. They give the solder a post to flow onto beside a component lead, and they give the female Dupont jumpers something to push onto — which is why the jumpers are fitted last and never soldered.

Fig 02.6-5 · 3D Visualizer · ns04-perfboard

02.6.5

Solder the 4-way angled header at J1
ns04-hdr-in
Fit the 4-way angled header into A7–A10, the board’s first row, with the pins leaving over the board’s edge. Solder one end pin, check the body is square against the edge, then do the rest.

NOTE · A7 is ＋5 V, A8 is GPIO18, A9 is logic ground, A10 is spare and connects to nothing. It is populated so the header has four posts to sit square on.

Fig 02.6-6 · 3D Visualizer · ns04-hdr-in

02.6.6

Solder the 2-way angled header at J2
ns04-hdr-out
Fit the 2-way angled header into T8–T9, the board’s last row, pins leaving over the opposite edge. T8 carries CTRL to the BuckPuck’s gray lead, T9 the control-ground reference to its green.

NOTE · Angled on both ends means the two harnesses leave the board flat and in opposite directions — input one side, output the other — so neither has to bend over the board to get out of the lamphouse.

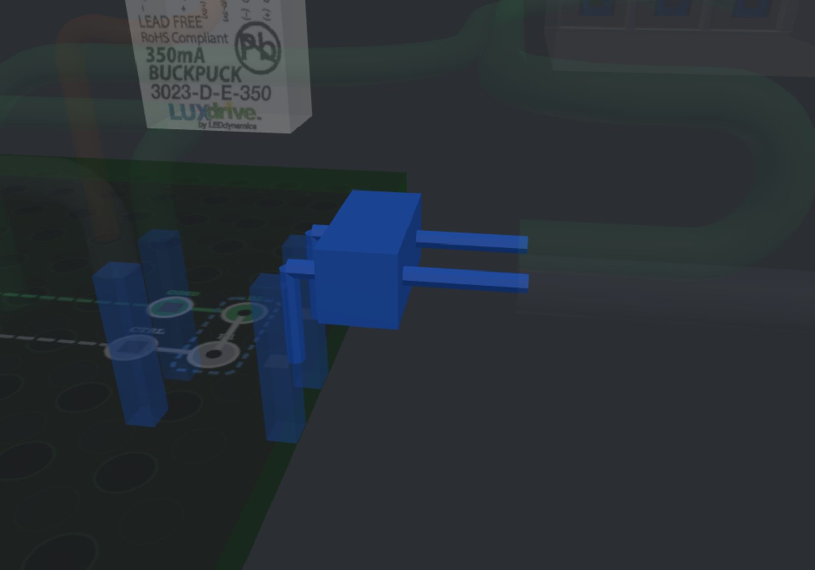
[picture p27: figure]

Fig 02.6-7 · 3D Visualizer · ns04-hdr-out

02.6.7

Solder the twelve joints that finish the circuit
ns04-perfboard
Everything is now in its own pad and none of it is connected. Work the solder map above, joint by joint: flow solder across each numbered pair until the two pads are one. Five of the twelve tie a male pin to a component lead, four tie a header pin to a male pin, two run across an empty pad to join two component leads, and one ties two male pins together.

HAZARD · Every pad on this board is ISOLATED — no strips, no copper between holes. Until a joint is made there is no circuit across it, and a board with every part fitted and no bridges flowed is an open circuit in twelve places. Nothing about it looks unfinished.

NOTE · Two of them — I6–I7–I8 and J10–J9–J8 — run across a pad that holds nothing. I7 and J9 exist only to be bridged over, carrying R1 into the base and R2 into the collector. Check each joint with a meter before you move on; a dry joint here looks exactly like a good one.

Fig 02.6-8 · 3D Visualizer · ns04-perfboard

02.6.8

Fig 02.6-8d · The twelve joints on THIS board, numbered as the legend numbers them. Generated from the board file, so it cannot disagree with the pads the components were fitted to.
Jumper B9 → H9 — ground
W.027
Run a BLACK jumper from B9 to H9. A9 brings logic ground in from Pi Pin 39 and solders to B9; this wire carries it to H9, which bridges to H8 — Q1's emitter.

NOTE · B9 is the single point. Everything on this board that needs ground references it and nothing else, which is what makes the control reference trustworthy.

Fig 02.6-9 · 3D Visualizer · W.027

02.6.9

Jumper C9 → S9 — control ground reference
W.023
Run a GREEN jumper from C9 to S9. B9 bridges to C9; this wire takes the reference out to S9, which bridges to T9 on the OUT header.

NOTE · Low current, and it must stay that way. It shares a node with the 350 mA return but never a path.

Fig 02.6-10 · 3D Visualizer · W.023

02.6.10

Jumper B7 → E10 — +5 V
W.024
Run a RED jumper from B7 to E10. A7 brings +5 V in from Pi Pin 2 and solders to B7; this wire carries it to E10, which bridges to F10 — R2's high side.

NOTE · That is the entire +5 V distribution on this board. R2 is the only thing drawing it.

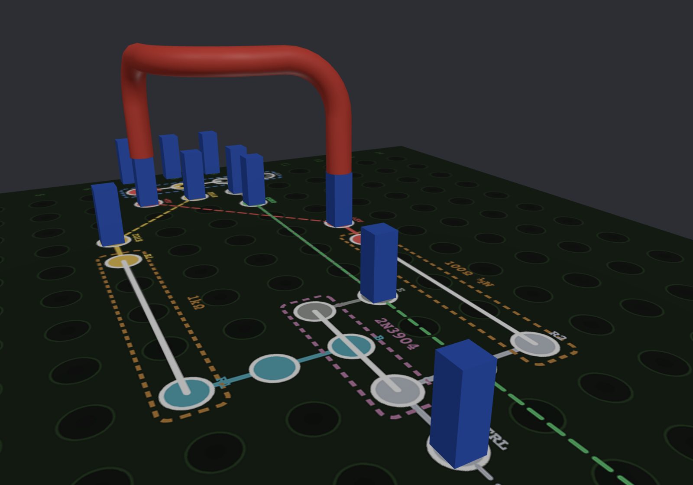
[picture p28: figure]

Fig 02.6-11 · 3D Visualizer · W.024

02.6.11

Jumper B8 → D6 — GPIO18
W.025
Run an ORANGE jumper from B8 to D6. A8 brings GPIO18 in from Pi Pin 12 and solders to B8; this wire carries it to D6, which bridges to E6 — R1's high side.

NOTE · This is the modulation. Everything the light does in time arrives on this one wire.

Fig 02.6-12 · 3D Visualizer · W.025

02.6.12

Jumper K8 → S8 — CTRL
W.026
Run a GRAY jumper from K8 to S8. Q1's collector bridges to K8; this wire carries CTRL to S8, which bridges to T8 on the OUT header.

HAZARD · CTRL is inverted — Q1 pulling it DOWN is what turns the LED on. An open circuit along here is a lamp stuck ON, not a lamp that stops working.

Fig 02.6-13 · 3D Visualizer · W.026

02.6.13

## 02.7 Mechanical Assembly — the Lamphouse Stack

ONLINE: ACTIVITY 02.7 · 3D VISUALIZER

The light element is built in your hand, the column is built on the enlarger, and the two are married at the end. Order is most of this activity: each piece closes access to the one under it, and two things -- the solder joints and the lead dressing -- are impossible to get at once the star is seated. What each part IS belongs to 02.2 and 02.4; this is how they go together.

Start at the star -- the heart of the module
cree-xpe2-star
Everything in this chapter exists to put current through one Cree XP-E2 on a 20mm hex metal-core board, and everything in the chapters after it exists to measure what comes out. Work on it first, on the bench, with the housing empty and the column untouched.

NOTE · Two stars, one at a time, same footprint and same driver: WHITE for bring-up, BLUE 470nm for calibration and every real exposure. Build with the white one.

Fig 02.7-1 · 3D Visualizer · cree-xpe2-star

02.7.1

Find the two pads, and which way the die faces
cree-xpe2-emitter
The 3.5mm die sits ON the board, and the board carries two pads: ＋ ANODE and − CATHODE. Note which is which NOW, with the board bare and the markings visible. The die faces DOWN the column once this is assembled.

HAZARD · Once the star is seated on the ring the pad markings are underneath your own wiring and under the ring's lip. If you are going to read them, read them here.

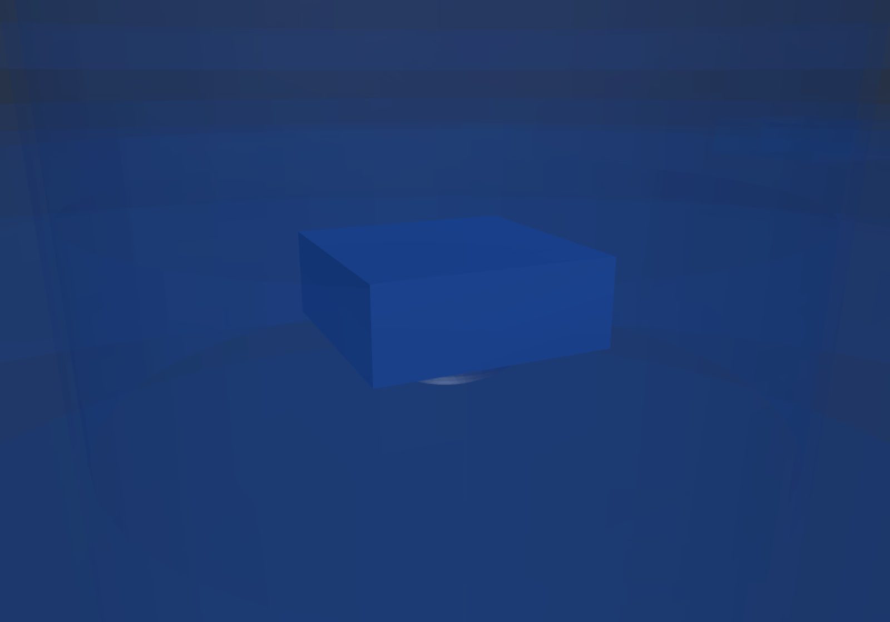
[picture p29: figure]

Fig 02.7-2 · 3D Visualizer · cree-xpe2-emitter

02.7.2

Solder the two legs -- and get the polarity right
cree-xpe2-star
Tin both pads, then land 18AWG on each: LED＋ from the BuckPuck to the ANODE pad, and the 350mA return from the CATHODE pad. Keep the iron on each pad only as long as it takes -- the board is aluminium and it pulls heat away from the tip, so a joint that looks bright can be cold underneath.

HAZARD · POLARITY IS NOT A CONVENTION HERE, it is the whole circuit. An LED is a diode: reversed, it does not light, and because the BuckPuck holds CURRENT rather than voltage nothing downstream complains about it. You get a dead lamp, a driver that looks healthy and a meter that reads plausibly -- and you will go looking for the fault everywhere except the two joints you just made.

NOTE · The polarity you set here is carried by every connection after it, through the WAGO ground star and back to the driver. Reverse it at the star and it is reversed for the whole build.

Fig 02.7-3 · 3D Visualizer · cree-xpe2-star

02.7.3

Train the leads before anything is seated
cree-xpe2-star
Dress the two legs away from the die, sleeve them, and wrap them along the housing so they leave on ONE side and in the direction they will travel -- which is UP, through the hollow centre of the mounting rod in the next step. Trained now, the star drops into place and the leads follow it. Untrained, you are feeding two stiff 18AWG legs up a 10mm bore inside an assembled stack with one hand.

HAZARD · No lead may sit between the star and the ring. A lead under the board lifts one edge of it, and a star that does not sit flat puts the die off the plane the whole optical column is measured from.

NOTE · Leave a service loop. The lamphouse is the one place in this build where a lead that is exactly long enough is too short.

Fig 02.7-4 · 3D Visualizer · cree-xpe2-star

02.7.4

The diffuser goes in FRONT of the LED, and it is not optional
carclo-optic
Thread the Carclo 10140 into the front of the housing -- the face that will point down the column -- so every photon the die emits passes through it. It spreads the emitter into an even field at a known angle. Do it with the housing in your hand: it is an easy turn now and an awkward reach once the housing is on the spacer.

HAZARD · Assemble without it, or with it loose, and the die images as a SPOT rather than a field. That gets worse as the aperture closes: at f/22 the projection is sharper and a hot spot is exactly what you see.

NOTE · APERTURE, while you are thinking about it. Diffuse light is what this instrument wants, not sharp light. f/8 is the working aperture. f/11 is acceptable. f/4 and below tends to be too bright, and f/22 buys sharpness you did not want at the cost of the evenness you did.

Fig 02.7-5 · 3D Visualizer · carclo-optic

02.7.5

Now it is one sub-assembly
dlh-1upeh
Housing, optic, star and two trained leads: that is the light element, finished, and it goes onto the column as a single piece. Everything from here is the column underneath it.

HAZARD · Handle the optic by its edge. A fingerprint on that face sits on the optical axis for the life of the build.

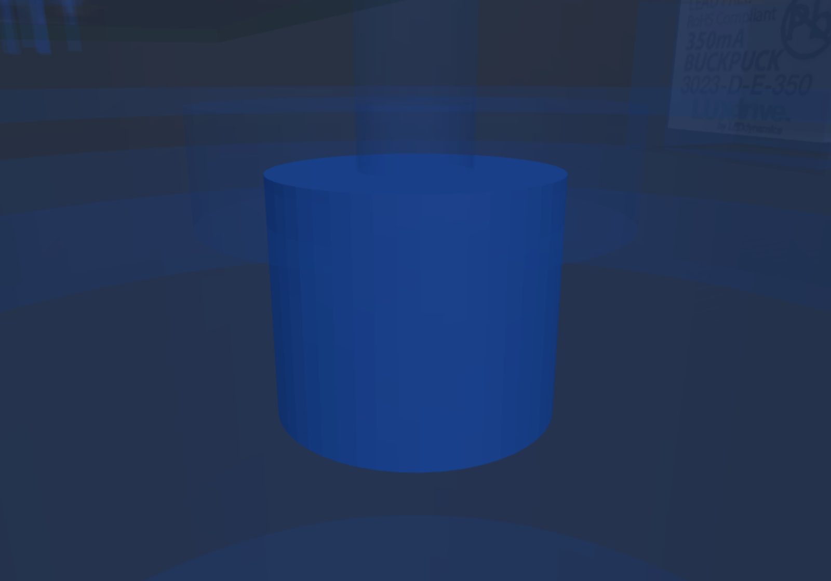
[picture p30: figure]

Fig 02.7-6 · 3D Visualizer · dlh-1upeh

02.7.6

The column starts at the seat
lightspacer-lower-ring
The spacer seat lands on the enlarger body. Get it flat and square before anything goes above it: every part after it inherits whatever tilt it has.

NOTE · It is the lowest part of the lamphouse at z 437 and the emitter ends up at z 541, so a degree of tilt here is a degree of tilt 100mm higher up.

Fig 02.7-7 · 3D Visualizer · lightspacer-lower-ring

02.7.7

Spacer next -- it sets the drop
lightspacer-large
The light spacer goes onto the seat. Its height IS the emitter-to-optics distance, so it is fitted before anything optical and not adjusted afterwards.

Fig 02.7-8 · 3D Visualizer · lightspacer-large

02.7.8

Land the light element on the spacer
dlh-1upeh
The sub-assembly goes down onto the spacer stack as one piece, leads leaving on the side you trained them to.

Fig 02.7-9 · 3D Visualizer · dlh-1upeh

02.7.9

Mount on the threaded rod -- lamp hardware, not printed hardware
lamp-rod
The assembly mounts to the light ring on a threaded HOLLOW metal rod -- the standard lamp-housing part, the kind that comes in any lamp kit. It protrudes directly through the CENTRE of the light ring, on the same axis the light takes, and takes a bolt and washer on the far side. That is the whole fixing: one pass-through, one bolt, one washer.

HAZARD · It also keeps the load and the heat OFF the plastic. The metal rod carries the assembly and isolates it from the PETG around it: a printed part asked to be the structural fixing in a warm lamphouse is a part that creeps, and a spacer that creeps moves the light. Let the metal take it.

NOTE · Hollow is the point. The trained leads run UP the centre of the rod, so the wiring leaves the lamphouse through the same part that holds it -- no second hole, no lead pinched between two faces, and the run is already pointing where it has to go next.

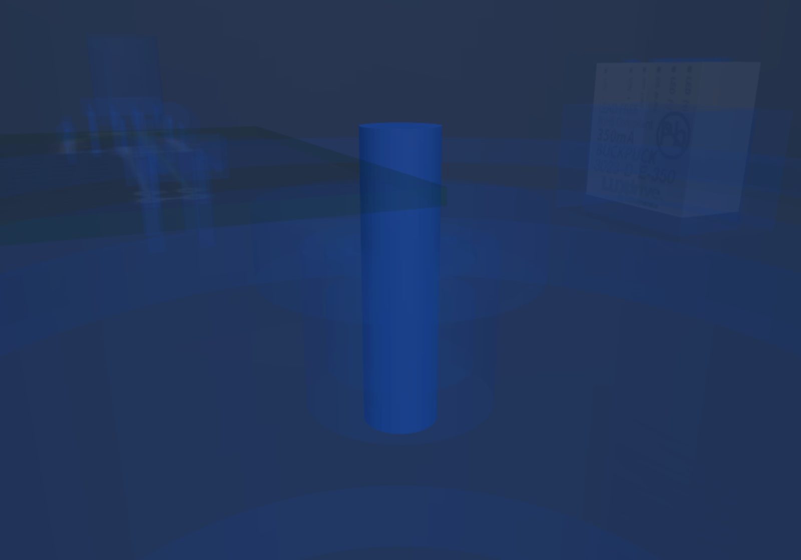
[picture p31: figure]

Fig 02.7-10 · 3D Visualizer · lamp-rod

02.7.10

Ring over the star -- and the view closes
cree-lightring
The light ring goes over the star and holds it on axis and on plane. The ring is a disc across the whole aperture: once it is on, nothing below it can be seen or reached without lifting it off again.

HAZARD · Last chance to check the die faces DOWN and both joints are sound. After this the only way back to them is back out through this ring.

Fig 02.7-11 · 3D Visualizer · cree-lightring

02.7.11

The lid goes on last -- and not yet
light-circuit-hat
The circuit lid closes the top and carries the control board on its four standoffs. Leave it OFF. The emitter's leads are reachable from above only while it is off, they are landed in 02.8, and the lid is fitted in 02.9 once the wiring is proved.

HAZARD · Fit it now and the next two activities mean taking it off again. Nothing under this lid can be reached through it.

Fig 02.7-12 · 3D Visualizer · light-circuit-hat

02.7.12

## 02.8 Emitter and Control Side Wiring

ONLINE: ACTIVITY 02.8 · 3D VISUALIZER

The 350 mA legs. Both are direct between the driver and the star — the schematic says so twice.

Identify the star's pads
cree-xpe2-star
Identify the anode and cathode on the star — a single Cree XP-E2 on a 20 mm metal-core board. They sit on opposite sides of the top face, anode toward the driver.

NOTE · White for bring-up, blue 470 nm for calibration. Same board, same driver — what changes is what the photometry means.

Fig 02.8-1 · 3D Visualizer · cree-xpe2-star

02.8.1

LED+ — driver to the star's anode
W.020
Run the ORANGE LED+ lead from the driver to the star's anode, dropping it through the light ring to reach the board. This leg carries 350 mA.

HAZARD · Direct, and only direct. Nothing may sit between the driver and the emitter on this leg.

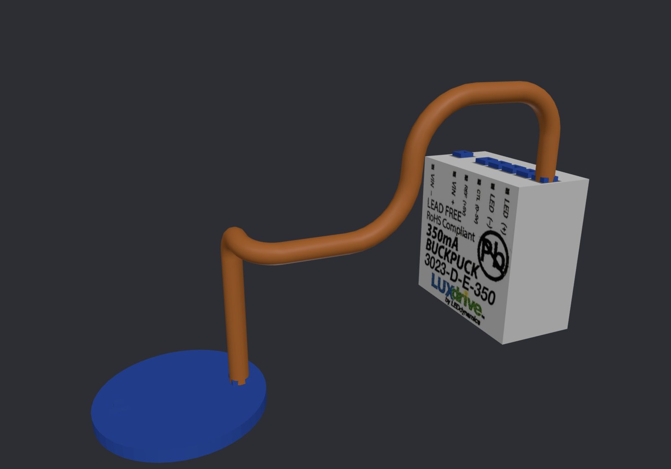
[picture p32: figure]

Fig 02.8-2 · 3D Visualizer · W.020

02.8.2

Fit the 3-way ground star
wago-led-gnd
Fit a WAGO 221-413 above the light ring. Three conductors meet here: the emitter's return, the driver's LED−, and the board's control-ground reference.

NOTE · One splice, so the reference and the return are at the same potential by construction. Meeting at two places would let the control voltage move with the LED current.

Fig 02.8-3 · 3D Visualizer · wago-led-gnd

02.8.3

Star cathode → ground star, way 1
W.021
Run a GREEN lead from the star's cathode back up through the light ring into way 1 of the ground star. This is the 350 mA return.

HAZARD · It carries the full drive current. Seat it properly — this splice wants a lever on all three, not a hand-twist.

Fig 02.8-4 · 3D Visualizer · W.021

02.8.4

Ground star way 2 → driver LED−
W.022
Run a GREEN lead from way 2 of the ground star to the BuckPuck's LED−. This completes the second half of the return.

Fig 02.8-5 · 3D Visualizer · W.022

02.8.5

Two wires out of the board's OUT header.

T8 → BuckPuck CTRL
W.013
Run a GRAY lead from T8 on the OUT header to the BuckPuck's CTRL input, carrying the board's collector output to the driver.

HAZARD · Open circuit here = full brightness. This wire failing is not a dark lamp.

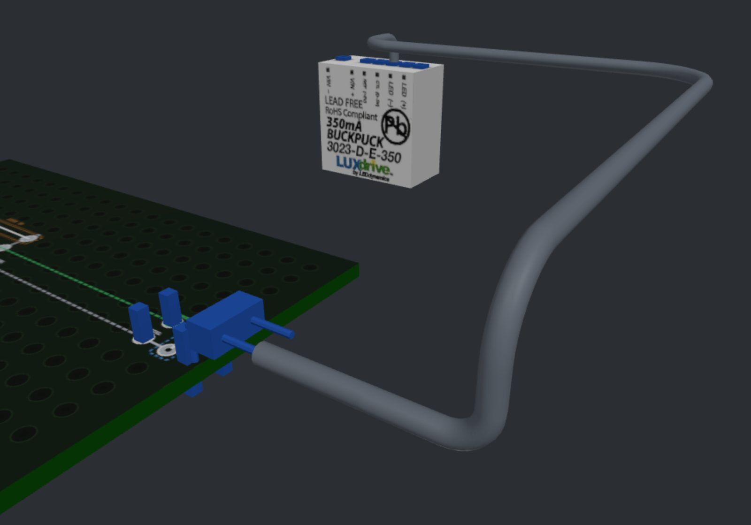
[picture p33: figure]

Fig 02.8-6 · 3D Visualizer · W.013

02.8.6

T9 → ground star, way 3
W.014
Run a GREEN lead from T9 to way 3 of the ground star, joining the control-ground reference to the same splice as the emitter return.

NOTE · Shares a node with 350 mA, never a path. That distinction is the whole reason the splice exists.

Fig 02.8-7 · 3D Visualizer · W.014

02.8.7

## 02.9 Into the Machine, Then Power, Then Prove

ONLINE: ACTIVITY 02.9 · 3D VISUALIZER

Three feeds from the GPIO breakout. All of them leave the light circuit through one hole.

Find the bore
light-circuit-hat
Locate the 12 mm bore dead centre in the hat's top plate. All five wires leaving the light circuit pass through it.

NOTE · The other holes in that plate are the board's standoffs. Do not thread anything through those.

Fig 02.9-1 · 3D Visualizer · light-circuit-hat

02.9.1

＋5 V — the breakout end (Pin 2)
W.010
Push the RED lead onto Pin 2 of the GPIO breakout. This is the board’s supply, and the only conductor on this run that can source current.

NOTE · Leave 2–3 in of straight off the header before the first bend. A terminal reached by a cable that turns immediately is under permanent tension.

Fig 02.9-2 · 3D Visualizer · W.010

02.9.2

＋5 V — the board end (A7)
W.010
Land the other end in A7 on the IN header. A7 is the board’s ＋5 V pad, and it bridges to B7 where the ＋5 V jumper starts.

NOTE · The run goes up the left wall, across the ceiling and down through the hat’s bore. All three Pi runs share that lane — dress them together.

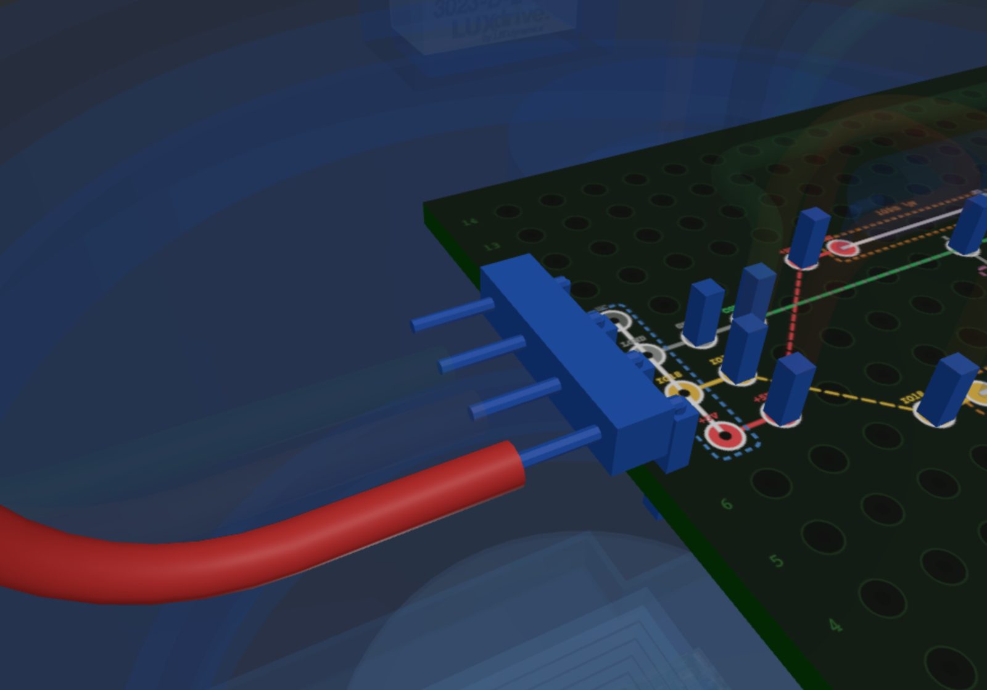
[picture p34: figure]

Fig 02.9-3 · 3D Visualizer · W.010

02.9.3

GPIO18 — the breakout end (Pin 12)
W.011
Push the ORANGE lead onto Pin 12 of the GPIO breakout. GPIO18 is the hardware-PWM pin: this is the wire the duty cycle travels down.

HAZARD · Meter the breakout before you trust its labels. A ribbon fitted 180° out mirrors all 40 pins, and ＋5 V arriving on a 3.3 V input will not announce itself.

Fig 02.9-4 · 3D Visualizer · W.011

02.9.4

GPIO18 — the board end (A8)
W.011
Land the other end in A8, in its own lane in the bundle. A8 bridges to B8, and the orange jumper carries it from there to R1.

Fig 02.9-5 · 3D Visualizer · W.011

02.9.5

Logic ground — the breakout end (Pin 39)
W.012
Push the GREEN lead onto Pin 39. This is the reference the whole control circuit is measured against.

NOTE · Pin 39 is a top-row pin, so it leaves upward. Pins 2 and 12 are bottom row and leave downward — approach an even pin from below, never across the top row.

Fig 02.9-6 · 3D Visualizer · W.012

02.9.6

Logic ground — the board end (A9)
W.012
Land the other end in A9. A9 bridges to B9, which feeds both the ground jumper and the control-ground reference leaving on the OUT header.

NOTE · Without this one lead the board has no common with the Pi and nothing switches. It does not half-work — it does not work.

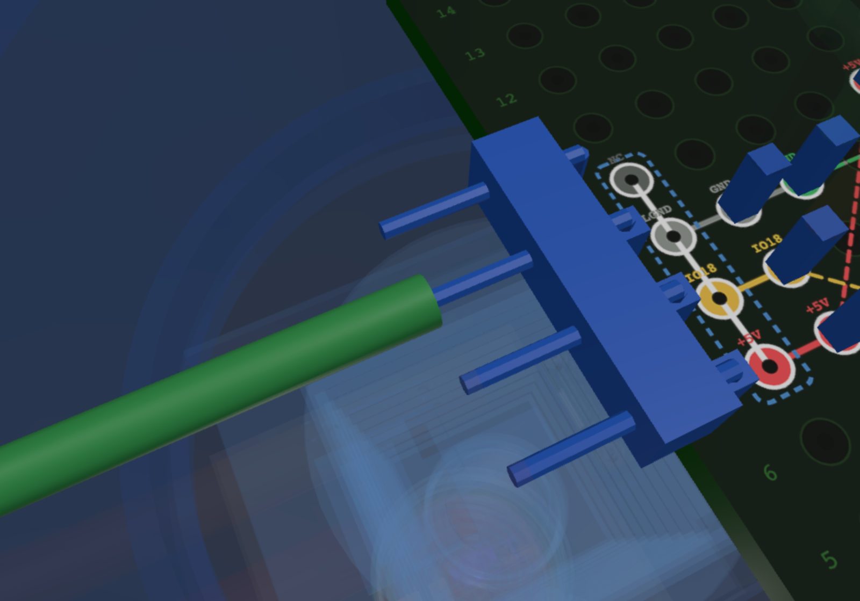
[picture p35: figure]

Fig 02.9-7 · 3D Visualizer · W.012

02.9.7

Nothing here is energised until the final step, and the two gates sit upstream of the driver.

Clip the bundle to the enclosure
cable-clip-01
Clip the bundle to the enclosure: one clip a short way off each bend, and one at the middle of each straight between them.

NOTE · A clip ON a corner fights the cable's own spring and works its screw loose. Beside the corner, it takes the load in shear.

Fig 02.9-8 · 3D Visualizer · cable-clip-01

02.9.8

Know the supply before you plug it in
psu15
Check the supply before you plug anything in: PSU15, +15 V, ≥0.75 A, centre-positive. It is the only part of the device that lives outside the enclosure. 15 V is a choice, not just a legal value: the 3-series string is ~10.5 V plus ~2 V of BuckPuck dropout, so the floor is ~12.5 V, and 24 V burns ~5 W as heat where 15 V burns ~2 W for the same light.

HAZARD · Check polarity before it goes near the jack. The driver runs on 13–24V, so a substituted brick can be within spec for the driver and badly wrong for a resistor chosen at 15V.

NOTE · Leave it unplugged. It is not energised until the last step of this section.

Fig 02.9-9 · 3D Visualizer · psu15

02.9.9

Fit the inlet
barrel-jack
Mount the barrel jack inside its bushing in the back panel, so the supply plug pushes in from outside without opening the cabinet.

NOTE · This is the breakaway point — the one connection meant to be pulled. The bushing takes the tug, not the jack's tails.

Fig 02.9-10 · 3D Visualizer · barrel-jack

02.9.10

Jack ＋ → inlet splice
W.019
Place the RED lead from the jack into a 2-way WAGO. The wire should sit ~51 mm off the floor, at the back.

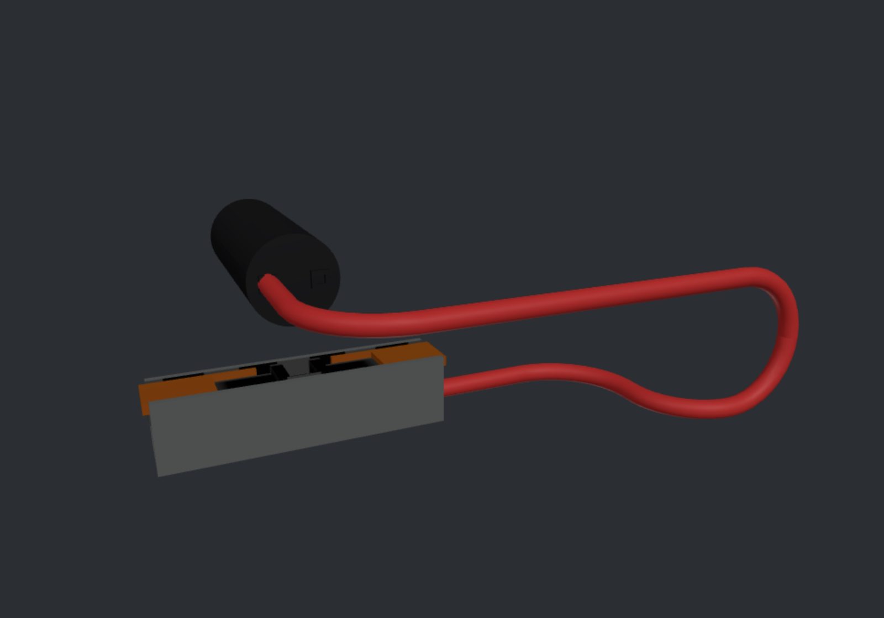
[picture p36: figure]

Fig 02.9-11 · 3D Visualizer · W.019

02.9.11

Supply rail — the inlet splice end
W.018
Land a second RED lead in way 2 of the inlet splice — the same 2-way WAGO the jack’s ＋ lead went into. The splice is what turns one jack tail into a rail.

NOTE · Up the back wall and along the ceiling from here. This is the longest single run in the device — measure it in place before you cut.

Fig 02.9-12 · 3D Visualizer · W.018

02.9.12

Supply rail — the SW1 end (upper lug)
W.018
Land the other end on SW1’s upper lug — the rail side. Bring it in through the ceiling of the switchbox so lifting the panel does not strain the joint.

NOTE · It shares one hole with the run coming back down, 12 mm apart. Two holes would be two chances to leak light.

Fig 02.9-13 · 3D Visualizer · W.018

02.9.13

SW1 lower lug → door interlock terminal 3
W.017
Run a RED lead from SW1's lower lug to terminal 3 of the door interlock — back down through the ceiling and along to the interlock.

Fig 02.9-14 · 3D Visualizer · W.017

02.9.14

Gated rail — the interlock end (terminal 4)
W.015
Land the RED lead on terminal 4 of the door interlock — the NO pair.

HAZARD · On terminals 1 and 2 instead — the NC pair — it does the exact inverse: dark with the door shut, live with it open. It would pass any casual test.

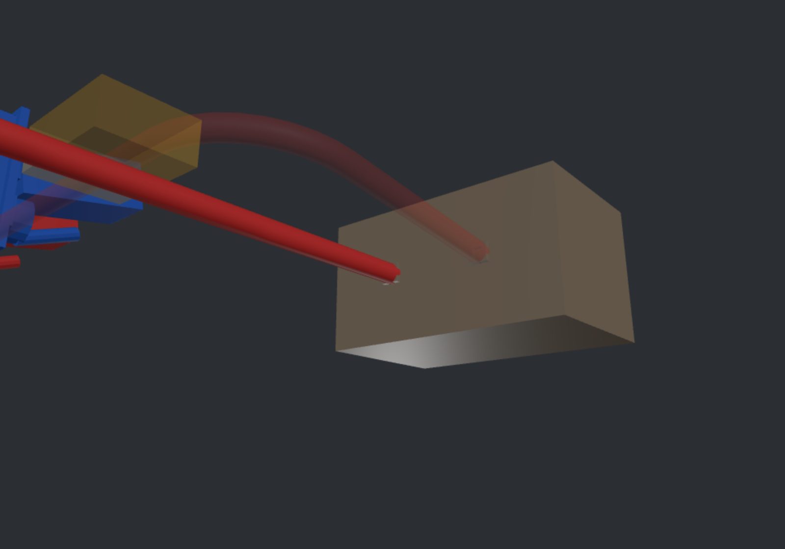
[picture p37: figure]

Fig 02.9-15 · 3D Visualizer · W.015

02.9.15

Gated rail — the BuckPuck end (Vin+)
W.015
Land the other end on the BuckPuck’s Vin+. This is the last leg of the gated supply: everything upstream of this terminal is switched, everything downstream is the driver’s to manage.

NOTE · Both gates are now upstream of the driver. An open circuit anywhere in this leg leaves the rail dark, which is the correct direction to fail.

Fig 02.9-16 · 3D Visualizer · W.015

02.9.16

Return — the BuckPuck end (Vin−)
W.016
Land the BLACK lead on the BuckPuck’s Vin−.

HAZARD · The return is NOT switched. Cutting the rail at SW1 or at the door does not isolate this conductor — it is referenced to the supply whenever the brick is plugged in.

Fig 02.9-17 · 3D Visualizer · W.016

02.9.17

Return — the jack end (− sleeve)
W.016
Land the other end on the jack’s − sleeve terminal. It runs beside the red for the whole drop.

NOTE · Beside, not twisted with. The pair is easier to trace and easier to replace when each lead keeps its own path.

Fig 02.9-18 · 3D Visualizer · W.016

02.9.18

Two checks before the first power, in this order. Both must fail dark.

Door open must be dark
With SW1 closed and the brick plugged in, open the door. Confirm the emitter goes out.

HAZARD · If it stays lit, the interlock is on the NC pair. Stop and rewire it to 3 and 4.

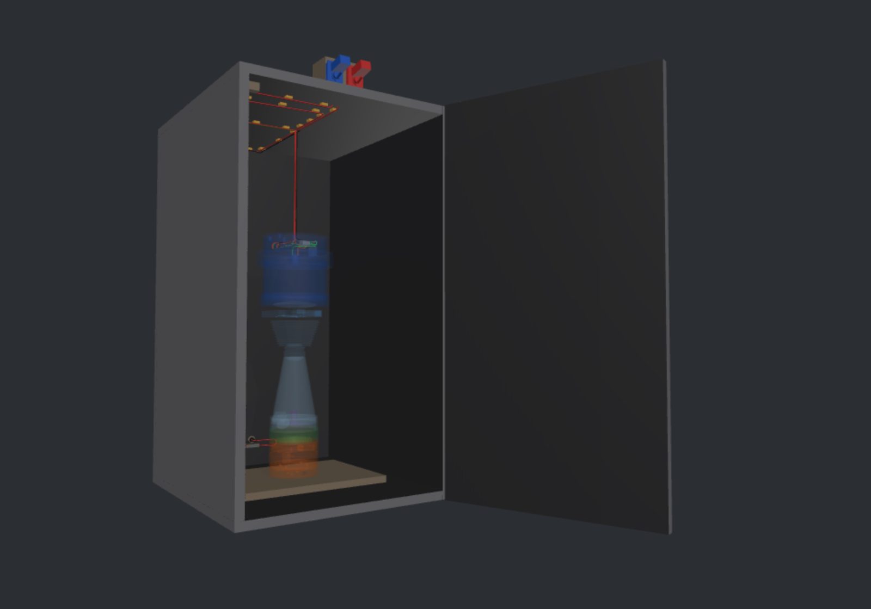
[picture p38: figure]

Fig 02.9-19 · 3D Visualizer ·

02.9.19

SW1 off must be dark
sw1-light
With the door shut and the brick in, open SW1. Confirm the emitter is out.

NOTE · Only once both gates have been shown to work is it reasonable to let the Pi drive CTRL for the first time.

Fig 02.9-20 · 3D Visualizer · sw1-light

02.9.20

On cable management
This guide gives you no cut lengths, on purpose. Leave a service loop where a run crosses a hinge, clip a bundle where it would otherwise hang on a connector, and dress it so the door can open through it without pulling. Look at how Photoplasm 1.0 was wired: those decisions were made, lived with, and are worth copying or improving on.

Stop here
Both checks above must fail dark before the Pi is allowed to drive CTRL for the first time. If the emitter stays lit on either, the interlock is on the wrong contact pair. Stop and rewire it.
© 2026 Eric Schneider · Beta 1.0 | edac8b1

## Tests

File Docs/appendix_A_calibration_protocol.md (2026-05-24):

Photoplasm Quick Start Guide  ·  Appendix A: Calibration Protocol

# Appendix A: Calibration Protocol

*Eric Schneider · Makerspace Charlotte · HTGAA 2026*

Version 0.1.0  ·  2026-05-17  ·  github.com/ericview-dev/photoplasm *Stepwedge Calibration, Light-Dose Quantification, and Incremental Exposure Protocols for Bacterial Reporter Systems using BioLight V5 (derived from eLightOn)*

> **DRAFT — Working Appendix.** This appendix is in active development. Section headings, protocol parameters, and figures are subject to revision as calibration data are collected. Placeholder values are indicated with `[TBD]`.

---

## **Overview**

Optogenetic control of gene expression in living bacterial cells requires a precise and reproducible relationship between the physical properties of the illumination source and the resulting biological output — in this case, measurable fluorescent protein expression. Without that relationship firmly established, any image, pattern, or dose delivered to a cell culture is an uncontrolled variable, and the experiment yields ambiguous data at best.

The concept of Photoplasm — the light-sensitive biological emulsion at the heart of the BioLight project — draws a deliberate analogy to photographic chemistry. A photographic emulsion responds to light exposure in a predictable, quantifiable way: the H&D (Hurter-Driffield) curve maps exposure to density, and every serious darkroom begins with a step-wedge calibration to characterize that curve before any image is committed to film. Photoplasm operates by the same logic. BioLight V5 is our optogenetic plasmid construct, developed from the eLightOn system — a blue-light–inducible transcription platform that established the core LOV-domain photosensory architecture we build upon. The bacterial reporter layer encoding BioLight V5 must be characterized before it can serve as a medium for biological imaging.

This appendix describes the stepwedge calibration protocol: a systematic, incremental exposure series applied to a uniform bacterial lawn under controlled conditions. The output is a biological dose-response curve — the Photoplasm equivalent of the H&D curve — which quantifies the relationship between light dose (irradiance × time, expressed as J/cm²) and normalized reporter output (relative fluorescence units, RFU, or optical density of colorimetric product). All subsequent imaging experiments depend on the valid operating range defined by this calibration.

## **1.  The Stepwedge: Concept and Rationale**

In classical photography, a stepwedge (also called a step tablet or neutral-density step wedge) is a series of optical density values arranged in discrete, evenly-spaced increments. When contact-printed onto photosensitive material, each step delivers a known, incrementally different exposure to the emulsion, producing a characteristic curve of response versus dose. The stepwedge is not an image — it is a measurement instrument.

In the BioLight context, the stepwedge is implemented as a spatial light modulator (SLM) pattern: a series of discrete rectangular zones, each programmed to transmit a defined fraction of total illumination intensity from the 470 nm LED array. The zones span from minimum to maximum exposure in consistent logarithmic steps. The biological emulsion — plated bacterial cells expressing BioLight V5 — is exposed beneath this pattern for a defined duration. After incubation and reporter development, each zone is imaged and its fluorescence output is quantified.

### **1.1  Why discrete steps rather than a continuous gradient**

Discrete steps are preferable to a continuous gradient for the calibration phase for three reasons. First, discrete zones allow independent statistical treatment of each exposure level. Second, the sharp edges between zones create unambiguous boundaries that facilitate automated image segmentation. Third, discrete steps map directly onto the digitally-controlled PWM (pulse-width modulation) output of the BioLight hardware: each step corresponds to a specific duty cycle setting, making conditions exactly reproducible in future experiments.

### **1.2  Relationship to device calibration**

The stepwedge protocol does not replace device calibration — it depends on it. Before any biological exposure is attempted, the BioLight illumination hardware must be characterized: the 470 nm LED array must deliver a known, spatially uniform irradiance (mW/cm²) at the substrate plane, and the PWM controller must translate duty cycle settings into delivered irradiance with a characterized response. This physical calibration is performed with a calibrated photodetector or spectrometer prior to any biological use.

Only after the device has been physically characterized does the stepwedge protocol begin. At that point, each step can be assigned a precise light dose in J/cm² (irradiance × exposure time), and the biological response can be plotted against a physically meaningful, absolute x-axis — not merely an arbitrary PWM setting.

| **Key Principle: Absolute Dose Units** All BioLight calibration data are recorded in J/cm² (joules per square centimeter). This ensures that calibration results are portable — comparable across hardware versions, labs, and setups — as long as the device has been characterized with a calibrated reference instrument. Never report calibration results in PWM duty cycle alone. |
| --- |

## **2.  Baseline Calibration Criteria**

Before the biological stepwedge experiment is run, the following baseline calibration criteria must be met and documented. Failure to meet any criterion should trigger re-calibration of the hardware before proceeding.

### **2.1  Hardware acceptance criteria**

| **Parameter** | **Value / Range** | **Notes** |
| --- | --- | --- |
| Peak irradiance at substrate | ≥ 0.5 mW/cm² | Measured at center of illumination field with calibrated sensor |
| Spatial uniformity | ≤ ±15% COV | Coefficient of variation across 9-point grid measurement |
| Spectral peak | 470 nm ± 5 nm | Verified by spectrometer or calibrated photodetector with bandpass filter |
| PWM linearity | R² ≥ 0.97 | Irradiance vs. duty cycle linear regression over 10–90% range |
| Temporal stability | < 5% drift over 60 min | Measured at fixed duty cycle; illumination source thermally stabilized |
| Dark chamber leakage | < 0.001 mW/cm² | At substrate plane with all LEDs off; ambient light excluded |

The hardware calibration record (device ID, date, operator, instrument serial number, and all measured values) must be appended to the experimental logbook before any biological experiment proceeds.

### **2.2  Biological baseline criteria**

The bacterial reporter system must also meet baseline performance criteria before calibration data are considered valid. These criteria are established using dark-control plates — cultures of the same BioLight V5 strain, prepared identically, but kept in complete darkness throughout the incubation period.

| **Parameter** | **Value / Range** | **Notes** |
| --- | --- | --- |
| Dark-control fluorescence (sfGFP) | < 50 RFU (normalized) | Leaky expression from uninduced promoter; establish per-batch |
| Dark-control melanin (tyrosinase) | OD₄₀₀ < 0.05 | Background pigmentation in unexposed zones |
| Colony density uniformity | ≤ 20% COV | Non-uniform lawns disqualify the plate |
| Agar surface clarity | No condensation | Condensation scatters light; allow plates to equilibrate before use |
| Incubation temperature | 37 °C ± 0.5 °C | For E. coli; temperature shifts alter expression kinetics |
| Post-exposure incubation | [TBD] hours | Time for full reporter maturation after illumination ends |

## **3.  Stepwedge Exposure Protocol**

### **3.1  Wedge design parameters**

The standard BioLight calibration stepwedge consists of ten discrete exposure zones arranged in a linear sequence across the illumination field. Zones span from 0% to 100% of maximum delivered dose in equal logarithmic steps, following photographic step-tablet convention (each step representing approximately a 0.30 log unit increase in exposure — a 2× doubling of dose).

| **Parameter** | **Value / Range** | **Notes** |
| --- | --- | --- |
| Number of steps | 10 | Zones 0–9; Zone 0 = minimum, Zone 9 = maximum |
| Step interval | ~0.30 log₁₀ units | Each step doubles the dose of the previous |
| Zone dimensions | [TBD] mm × [TBD] mm | Must contain ≥ 50 colony-forming units per zone |
| Illumination wavelength | 470 nm | Matches BioLight V5 / eLightOn LOV domain absorption peak |
| Dose range | [TBD] – [TBD] J/cm² | Spans sub-threshold to saturation; set from device calibration |
| Exposure duration | [TBD] minutes | Fixed for all zones; dose variation achieved by PWM irradiance control |
| Spatial light modulator | ILI9341 TN LCD | BL/LED pin to GND; 470 nm transilluminator as sole source |

### **3.2  Step-by-step protocol**

The following protocol assumes that hardware calibration criteria (§2.1) have been verified and logged, and that a fresh batch of BioLight V5 reporter plates has met biological baseline criteria (§2.2).

- Prepare the bacterial emulsion layer: inoculate LB-agar plates with the BioLight V5 reporter strain to a uniform lawn density. Use a calibrated cell-spreading protocol (100 µL of OD₆₀₀ = 0.1 suspension spread to confluence). Allow plates to dry in the dark at room temperature for 20–30 minutes before use.

- Equilibrate the dark chamber: bring the BioLight enclosure to operating temperature. Verify that the frustum cone is seated correctly and that the spacer ring stack is set to the validated working distance.

- Load the stepwedge pattern: transfer the calibrated stepwedge image file to the ILI9341 display controller via the Flask/Pi pipeline. Verify that the display is rendering the correct 10-zone gradient pattern with no backlight contribution (BL pin confirmed to GND).

- Zero the exposure timer: confirm that the Pi 5 PWM output (GPIO18, PWM0) is at 0% duty cycle. Log the start time, plate ID, operator, and chamber conditions.

- Initiate exposure: set PWM duty cycle to the calibrated maximum value corresponding to the desired Zone 9 peak dose. Start the exposure timer. The SLM pattern modulates intensity spatially across the plate; the PWM controls the global illumination level.

- Maintain exposure for the defined duration (§3.1). Monitor for thermal drift using the 1-Wire temperature sensor (Pin 7, GPIO4). If temperature deviation exceeds ±1 °C, log the event; deviations >2 °C disqualify the run.

- Terminate exposure: set PWM duty cycle to 0%. Log end time and total elapsed duration. Remove plate from the dark chamber and immediately wrap in aluminum foil to prevent ambient light exposure.

- Incubate the exposed plate in darkness at 37 °C for the post-exposure incubation period defined in §2.2. This allows full maturation of the sfGFP chromophore (estimated 60–90 min for mature fluorescence) or melanin deposition ([TBD] hours for tyrosinase-dependent output).

- Image the plate: using the AS7341-WS spectral analysis module, capture fluorescence or absorbance data from each of the 10 zones. Record raw values per zone without normalizing at this stage.

- Record all data immediately in the experimental logbook: plate ID, device calibration record ID, exposure parameters, raw zone measurements, and any anomalies observed during the run.

| **Critical: One Variable at a Time** The stepwedge calibration holds all parameters constant except light dose. Never vary exposure duration, temperature, strain preparation, or media composition between zones within a single calibration run. If any of these variables must be explored, they require independent experimental series. |
| --- |

## **4.  Interpreting the Calibration Curve**

### **4.1  Constructing the Photoplasm H****&****D curve**

After imaging, plot normalized reporter output (y-axis: RFU or absorbance, normalized to Zone 9 maximum) against log₁₀ of delivered dose (x-axis: log₁₀ J/cm²) for each of the ten zones. This plot is the biological H&D curve for the current batch of Photoplasm using BioLight V5 — the foundational dataset for all downstream imaging experiments.

The curve will typically display three regions analogous to those of a photographic characteristic curve:

- Toe region (sub-threshold): zones at low dose where reporter output is indistinguishable from the dark control. Defines the minimum effective dose (MED) — the threshold below which the system does not respond.

- Linear region (dynamic range): the dose interval over which reporter output increases monotonically and approximately linearly with log dose. This is the valid operating range for biological imaging.

- Shoulder region (saturation): zones at high dose where output plateaus. Defines the maximum useful dose; exposures above this threshold produce uniformly saturated output with no tonal discrimination.

### **4.2  Defining the valid exposure range for image experiments**

For any subsequent biological imaging experiment to be interpretable, the full range of doses delivered must fall within the linear region of the calibration curve:

- The minimum dose delivered (darkest shadow region of the image) must exceed the MED established by the stepwedge.

- The maximum dose delivered (brightest highlight region of the image) must fall below the shoulder threshold.

- The dose range of the image must not exceed the dynamic range of the linear region.

These constraints are analogous to the Zone System in photography: the image must be exposed so that all tonal information falls within the linear recording range of the medium. In BioLight, this is achieved by selecting the appropriate combination of peak irradiance (PWM duty cycle) and exposure duration to place image highlights at approximately 80% of the saturation dose.

| **Design Note: Calibration Batch Dependency** The H&D calibration curve is specific to a single preparation batch of BioLight V5 reporter cells, a single agar lot, and a single device calibration state. Any change in strain, media, incubation conditions, or hardware requires a new stepwedge calibration run. Calibration data must never be transferred between batches without biological validation. |
| --- |

## **5.  Integration with the BioLight Imaging Workflow**

The stepwedge calibration occupies Stage 1 in the BioLight experimental pipeline — characterize the medium, then expose the image.

| **Stage** | **Action** | **Dependency** |
| --- | --- | --- |
| Stage 0 | Dark chamber validation — verify spatial uniformity and spectral purity | Hardware acceptance criteria (§2.1) |
| **Stage 1** | Stepwedge calibration — establish biological H&D curve for current BioLight V5 batch | This appendix |
| Stage 2 | Image exposure (Aim 1A/1B) — single-output bacteriography within valid range | Relies on Stage 1 linear region |
| Stage 2 | Dual-output exposure — two-channel BioLight V5 image; sfGFP + tyrosinase reporters | Both reporters independently calibrated |
| Stage 3 | Analysis and quantification — zone fluorescence / OD measurement, image reconstruction | AS7341-WS spectral data or widefield imaging |

The Rasterizr pipeline — which converts SVG image files into exposure pattern arrays for the SLM — operates downstream of Stage 1. Rasterizr assigns dose levels to each pixel as a fraction of the calibrated maximum dose, ensuring that translated image exposures always fall within the validated linear range. This is the biological equivalent of pre-visualization in the Ansel Adams Zone System: the image is pre-interpreted in terms of the medium's tonal response before a single cell is illuminated.

Future iterations of this workflow will incorporate closed-loop feedback between the AS7341-WS spectral sensor and the PWM controller, allowing real-time dose adjustment to compensate for batch-to-batch variability in BioLight V5 reporter sensitivity. This capability is designated Stage 4 in the BioLight development roadmap and is not described in the current chapter.

## **6.  Safety and Containment**

All experiments described in this appendix use Biosafety Level 1 (BSL-1) E. coli strains under standard laboratory containment practices. The following precautions apply specifically to the BioLight illumination setup:

- 470 nm LED arrays at the irradiances used in BioLight protocols pose a low-level blue-light hazard. Avoid direct viewing of the illuminated field. Use appropriate eye protection rated for blue-light wavelengths during hardware calibration and extended operation.

- All biological materials — exposed plates, spent cultures, and contaminated labware — must be autoclaved or chemically decontaminated before disposal per institutional biosafety protocols.

- The dark chamber frustum cone and spacer rings (PETG, Bambu-printed) are not autoclavable at standard cycle temperatures. Decontaminate all inner surfaces with 70% ethanol before and after each experimental session.

- Tyrosinase-expressing BioLight V5 cultures produce melanin as a metabolic product. Melanin-containing agar plates should be handled as potentially hazardous waste and disposed of per institutional guidelines.

## **7.  Open Items and Next Steps**

The following items are outstanding as of this draft and must be resolved before this appendix is considered complete:

- [TBD] Determine post-exposure incubation time for full sfGFP chromophore maturation at 37 °C using the BioLight V5 construct. Literature baseline for eLightOn-derived systems: 60–90 min for fast-folding sfGFP variants; empirical confirmation required for BioLight V5.

- [TBD] Determine optimal plate lawn density (CFU/cm²) for stepwedge zone resolution. Too sparse → discontinuous reporter signal; too dense → nutrient limitation artifacts.

- [TBD] Characterize dark-control baseline RFU and OD₄₀₀ for the BioLight V5 strain and current agar lot. Values in §2.2 are placeholders.

- [TBD] Define zone dimensions based on finalized ILI9341 display resolution and optical throw distance at validated spacer height.

- [TBD] Establish post-exposure incubation time for tyrosinase/melanin output — likely longer than sfGFP maturation time.

- [TBD] Integrate AS7341-WS zone measurement protocol and confirm channel-to-channel cross-talk characterization for sfGFP (peak ~510 nm) vs. melanin (broadband absorption).

## **References**

Jayaraman, P. et al. (2016). Cell-free optogenetic gene expression system. ACS Synthetic Biology, 5(12). PMC5001607.

Levskaya, A. et al. (2005). Engineering Escherichia coli to see light. Nature, 438(7067), 441–442.

Motta-Mena, L. B. et al. (2014). An optogenetic gene expression system with rapid activation and deactivation kinetics. Nature Chemical Biology, 10, 196–202. [eLightOn / EL222 foundational work]

Fernandez-Rodriguez, J. et al. (2017). Genetic encoding of a far-red fluorescent protein optimized for forward genetic screens in living cells. Nature Chemical Biology, 13, 706–708.

Li, X. et al. (2020). Two-component optogenetic toolkit for the dynamic and spatiotemporal control of gene expression. ACS Synthetic Biology. PMC7102963.

Prokaryote Playhouse (open-source enclosure design). PMC9041274.

Adams, A. (1981). The Negative. New York Graphic Society. [Zone System reference for exposure methodology analogy.]

---

*Photoplasm · HTGAA 2026 · Genspace Node · Eric Schneider · Makerspace Charlotte*

*Repository: github.com/ericview-dev/photoplasm · branch: dev*

> v0.1.0  ·  2026-05-17  ·  draft

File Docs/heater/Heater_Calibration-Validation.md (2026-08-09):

# Heater Calibration Run — Validation Guide

**Photoplasm Incubation Heater · Stage 4 · First deliberate heat — characterize cold→max**
*Board: SpacePlacer v0.6 layout + V8 incoming routing*

---

## What this validates & who it's for

This is the **first time the heater is deliberately energized.** The goal is twofold: confirm the heater actually heats on command and the sensor tracks it, then **characterize the thermal response** — log DS18B20 temperature vs. time from cold up to plateau, producing the cold→max curve and a stored CSV. That data is what the closed-loop setpoint control is built on.

You need the prior stages passed, the Pi with the scripts loaded, and to be **present the entire time** — this stage produces real heat and must not run unattended on its first characterization.

**What changes here:** every stage until now proved the heater stays *off*. This one turns it *on*. So the safety model shifts from "confirm dormant" to "heat within bounds, with a hard cutoff and a human watching."

## Where this fits in the sequence

| | Document | Gate |
|---|---|---|
| ← before | Heater 12 V Power-On — Validation | **PASSED** (12 V held, heater off) |
| **▶ you are here** | **Heater Calibration Run** | heats on command, sensor tracks, curve + CSV captured, cools down |
| → next | Heater Closed-Loop Control | setpoint + hysteresis, interval logging |

---

## Safety measures

**The new hazard is uncontrolled heating.** Three layers guard against it:

1. **The PTC is self-limiting.** A PTC ceramic element's resistance rises sharply near its Curie point, so it naturally plateaus at its design temperature rather than running away like a resistance-wire heater. This is inherent, not software.
2. **Hard software over-temp cutoff.** `heater_calibration.py` forces the gate LOW the instant the sensor reads ≥ `MAX_TEMP_C` (default 50 °C). It also fails safe on any sensor read/CRC failure, on a runtime cap, on Ctrl-C, and on exit — the script cannot leave the heater on.
3. **You, watching.** First heat is attended. The cutoff is a backstop, not a babysitter.

> ### ⚠️ Sensor lag — the element is hotter than the reading
> The DS18B20 measures the chamber, not the PTC surface, and it lags. When the sensor reads 40 °C, the element is hotter. So keep the first run short, start with a conservative cutoff, and don't let the sensor number lull you — a hand near the supply switch beats any threshold.

**Abort (kill 12 V / Ctrl-C) if:**
- Temperature climbs far faster than expected, or overshoots the cutoff without the gate dropping
- Any smell, discoloration, or the board/PTC gets hotter than the sensor suggests
- The sensor reads erratically (the script should already cut the gate on a bad read)
- Anything unexpected — stop first, diagnose after

---

## What you need

- **12 V Power-On Validation: PASSED.** 12 V live, gate holding the heater off, grounds unified.
- Scripts on the Pi (in `~/photoplasm_git/heater/`): `heater_calibration.py`, `plot_calibration.py`.
- matplotlib for plotting: `pip install matplotlib --break-system-packages`
- Sensor confirmed reading (`28-33e70087fda7`). Meter handy (DC volts) for spot-checks.
- **Present and attending the whole run.**

### Behavior reference (low-side switch)
- Gate LOW → MOSFET off → no current → drain (T-6) floats ~12 V → **heater OFF**
- Gate HIGH → MOSFET on → drain pulled ~0 V → current through PTC → **heater ON, heating**
- The script confirms the transition by the temperature *rising*; you can spot-check the drain dropping toward 0 V when it's ON.

---

## Procedure

Run attended, one phase at a time. **Do the pulse test before the full run.**

### Step 0 — Entry state
- [ ] 12 V Power-On passed; 12 V live; gate low; board cool.
- [ ] `cat /sys/bus/w1/devices/28-33e70087fda7/w1_slave` → valid read, sane ambient temp.
- [ ] Scripts present; you're at the bench, hand near the supply switch.

### Step 1 — Functional pulse test (first heat, short)
Confirms the heater heats and the sensor tracks — *before* any sustained run.
- [ ] Run a short pulse (30 s):
      ```bash
      python3 heater_calibration.py --pulse 30
      ```
- [ ] Watch the live print: baseline prints, then `GATE HIGH`, then temperature should **start rising** within the 30 s.
- [ ] *(Optional meter spot-check while it's ON)* drain (T-6) ↔ GND should now read **near 0 V** (MOSFET conducting), versus the ~8 V float when off.
- [ ] At 30 s the script prints `PULSE_END` and forces the gate LOW.
- [ ] **Confirm cooldown:** temperature stops rising and begins to fall. Heater responds to OFF.
- [ ] Board check: warmth at the PTC is expected now; the MOSFET should be only mildly warm, wiring/Wagos cool.

**Gate:** temperature rose on command and fell on release, no surprises → proceed. If it didn't heat, stop and troubleshoot (below) before the full run.

### Step 2 — Full calibration run (cold → plateau/cutoff)
- [ ] Let the chamber return near ambient first (so the curve starts cold).
- [ ] Start the run:
      ```bash
      python3 heater_calibration.py
      ```
      *(For an extra-cautious first characterization, lower the ceiling: `--max-temp 45`.)*
- [ ] Watch the live temperature print the whole time. The run ends automatically on **plateau**, **MAX_TEMP cutoff**, or the **runtime cap** — whichever comes first — and forces the gate LOW.
- [ ] It writes `heater_calibration_<timestamp>.csv`.

### Step 3 — Confirm safe shutdown & cooldown
- [ ] Gate LOW at end (script confirms "Gate LOW, GPIO released").
- [ ] Temperature falling. Board cooling.
- [ ] *(Meter)* gate ↔ GND back to ~0 V; drain back to ~floating.

### Step 4 — Plot & review the curve
- [ ] Plot it:
      ```bash
      python3 plot_calibration.py heater_calibration_<timestamp>.csv
      ```
- [ ] Review the PNG: shape of the rise, the plateau (or cutoff) value, and where **37 °C** falls on the curve (marked on the plot). Note the approximate time to reach 37 °C and the plateau temperature.

---

## What a pass looks like

- [ ] Pulse test: temperature rose on gate-HIGH, fell on gate-LOW
- [ ] Full run: logged cold→plateau/cutoff without incident; gate forced LOW at end
- [ ] Fail-safes behaved (cutoff/plateau/runtime triggered cleanly; no runaway)
- [ ] CSV written and plotted; 37 °C reachable and located on the curve
- [ ] Board within expected temps (PTC warm, MOSFET mild, wiring cool)

→ **PASS = the heater is controllable and characterized. Cleared for Closed-Loop Control.**

**Capture for the record:** baseline (cold) temp, plateau/max temp, approximate time-to-37 °C, and the cutoff used. These set the setpoint/hysteresis and expected timing for the control stage.

## Troubleshooting

| Symptom | Likely cause | Action |
|---|---|---|
| No temperature rise on gate-HIGH | MOSFET not switching; gate not reaching HIGH; open in PTC path | Stop. Meter: gate should be ~3.3 V when commanded HIGH; drain should drop to ~0 V. Recheck T-5 12 V and T-6→drain path |
| `ABORT_SENSOR_START` | sensor not read at launch | Recheck the DS18B20 (address, T-8 ground); re-run Logic Power-On sensor check |
| Cuts out fast with `SENSOR_FAULT` | intermittent sensor read mid-run | Check the sensor data/ground joints; the T-8 ground especially |
| Hits `MAX_TEMP_CUTOFF` very quickly | heating faster than expected, or cutoff set low | Fine for safety; if you want the full curve, let it cool and raise `--max-temp` cautiously |
| MOSFET runs hot | high current / marginal switching | Stop; a low-side MOSFET should stay fairly cool switching a PTC — investigate before longer runs |
| Chip error on launch | wrong gpiochip number | Edit `CHIP` in the script (Pi 5 sometimes needs `4`) |

---

## Sign-off

| Field | Value |
|---|---|
| Date | __________ |
| Pulse test: temp rose / fell | __________ |
| Baseline (cold) temp (°C) | __________ |
| Plateau / max temp (°C) | __________ |
| Cutoff used (°C) | __________ |
| Approx. time to 37 °C (s) | __________ |
| CSV filename | __________ |
| MOSFET / board thermal | __________ |
| **Result** | **PASS / FAIL** |
| Tested by | __________ |

Notes: ________________________________________________________________

---

## Recommended prompt (to expedite with an assistant)

```
I'm running the Heater Calibration Run for my Photoplasm incubation heater
(Raspberry Pi 5, board: SpacePlacer v0.6 + V8 routing). Context:

- Continuity, Logic Power-On, Ground Path, and 12 V Power-On all PASSED. 12 V
  is live; the heater has been held off and is now cleared to energize.
- Low-side MOSFET (IRLZ44N: F8 gate / G8 drain / H8 source). Gate HIGH = heat.
  DS18B20 sensor 28-33e70087fda7. Scripts: heater_calibration.py (has --pulse
  SEC mode and a hard MAX_TEMP cutoff, default 50 C, fail-safe gate-LOW on
  sensor fault / runtime / exit) and plot_calibration.py.
- This is the FIRST deliberate heat. Do the --pulse 30 functional test FIRST
  (confirm temp rises then falls), then the full run to plateau/cutoff, then
  plot. The sensor lags the PTC surface, so keep it attended and conservative.

Walk me through it ONE STEP AT A TIME: a single step, wait for my result
(live temp / CSV / observation), confirm against what's expected, then
continue. Enforce the abort criteria. Start with the short pulse, not the
full run.
```

## Next step

On a clean pass, proceed to **Heater Closed-Loop Control**: use the plateau and timing from this run to set a target (37 °C) with a min/max hysteresis band that switches the gate on/off, logging sensor values at a chosen interval (≥1 s), with the hard over-temp cutoff retained as a standing guard. That's the final stage — a controllable, self-regulating incubation heater.

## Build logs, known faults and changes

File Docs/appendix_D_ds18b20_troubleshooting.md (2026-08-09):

Photoplasm Quick Start Guide  ·  Appendix D: DS18B20 1-Wire Sensor — Wiring & Troubleshooting

# Appendix D: DS18B20 1-Wire Sensor — Wiring & Troubleshooting

*Eric Schneider · Makerspace Charlotte · HTGAA 2026*

Version 1.0.0  ·  2026-06-12  ·  github.com/ericview-dev/photoplasm

---

## Overview

This appendix documents the correct wiring for the DS18B20 waterproof temperature sensor on the Heater Perfboard, the software setup required to activate the 1-Wire bus, and a systematic troubleshooting guide derived from the first bench build. The gotchas documented here were encountered and resolved during initial hardware bring-up.

---

## Correct Wiring

The DS18B20 uses the Dallas 1-Wire protocol on a single GPIO pin. A 4.7kΩ pull-up resistor (R2) holds the data line at 3.3V when idle. The sensor pulls the line low briefly to communicate.

```
Pi Pin 1  (3.3V) ──── R2 (4.7kΩ) ────┬──── J1 pin 3 (DS18B20 Data, orange wire)
                                       │
Pi Pin 7  (GPIO4 / 1-Wire) ───────────┘

Pi Pin 39 (GND) ────────────────────── J1 pin 4 (DS18B20 GND, gray wire)
Pi Pin 1  (3.3V) ───────────────────── J1 pin 5 (DS18B20 VDD, blue wire)
```

### The critical junction

The bottom leg of R2, J1 pin 3 (data wire), and the jumper to GPIO4 must all connect at the **same perfboard node** — same row of holes, linked by solder bridges or a jumper wire. If any one of these three is not at the same node, the pull-up will not reach the sensor and the Pi will not see the data signal.

---

## JST Connector Pinout (J1)

| Pin | Label | Function | Wire Color |
|---|---|---|---|
| 3 | T7 / J3 | DS18B20 Data | Orange |
| 4 | T8 / J4 | DS18B20 GND | Gray |
| 5 | T9 / J5 | DS18B20 VDD (3.3V) | Blue |

---

## Raspberry Pi Pin Reference

| Pi Pin | GPIO | Function |
|---|---|---|
| 1 | — | 3.3V → R2 pull-up top, DS18B20 VDD |
| 7 | GPIO4 | 1-Wire data |
| 39 | — | GND → DS18B20 GND |

**Note:** All GND pins on the Pi (6, 9, 14, 20, 25, 30, 34, 39) are electrically identical — the same ground plane. Pin 39 can be used if Pin 6 is occupied by another subsystem (e.g. the LED ring).

---

## Software Setup

Enable the 1-Wire overlay in the Pi boot config:

```bash
sudo nano /boot/firmware/config.txt
```

Add at the bottom:

```
dtoverlay=w1-gpio,gpiopin=4
```

Save and reboot:

```bash
sudo reboot
```

Verify sensor detection after reboot:

```bash
ls /sys/bus/w1/devices/
```

A working sensor shows a device starting with `28-` alongside `w1_bus_master1`. Read temperature:

```bash
cat /sys/bus/w1/devices/28-*/w1_slave
```

A valid response ends with `YES` and a temperature in thousandths of a degree Celsius:

```
86 01 00 00 7f e1 3c aa d3 : crc=d3 YES
86 01 00 00 7f e1 3c aa d3 t=24375
```

`t=24375` = 24.375°C (75.9°F). `YES` confirms the CRC passed — the reading is valid.

---

## Troubleshooting

### Step 1 — Check the overlay is loaded

```bash
cat /boot/firmware/config.txt | grep w1
```

Should return: `dtoverlay=w1-gpio,gpiopin=4`

If blank, the line was not saved. Add it and reboot.

---

### Step 2 — Check the bus master appears

```bash
ls /sys/bus/w1/devices/
```

| Result | Meaning |
|---|---|
| `w1_bus_master1` only | Overlay loaded, bus active, sensor not detected |
| `28-xxxxxxxxxxxx` + bus master | Sensor detected — proceed to temperature read |
| Empty | Overlay not loaded or GPIO4 not reaching the bus |

---

### Step 3 — Measure data line voltage (Pi powered on)

Probe the data line (J1 pin 3 or the junction node on the perfboard) with a multimeter.

| Voltage | Meaning |
|---|---|
| 3.0–3.3V | Pull-up working, sensor idle — check GPIO4 connection |
| ~0.5V | Something pulling the line low — see Step 4 |
| ~0V | No pull-up reaching the data node — check R2 wiring |

---

### Step 4 — Isolate sensor vs GPIO4

If the data line reads ~0.5V with the sensor connected:

1. **Power off the Pi** (`sudo shutdown now`, unplug)
2. **Disconnect the JST connector** — remove the sensor entirely
3. **Power the Pi** and measure the data line voltage at the perfboard node

| Voltage with sensor disconnected | Meaning |
|---|---|
| Rises to 3.3V | DS18B20 is damaged — replace the sensor |
| Stays at ~0.5V | GPIO4 is being driven low by the Pi — check overlay and GPIO config |

---

### Step 5 — Continuity checks (Pi powered off)

| Check | Probe points | Expected |
|---|---|---|
| R2 in pull-up path | Sensor data wire → 3.3V rail | ~4.7kΩ (R2 resistance) |
| Data node to GPIO4 | Perfboard data junction → Pi Pin 7 | Continuity (beep / ~0Ω) |
| DS18B20 GND | J1 pin 4 → Pi GND pin | Continuity (beep / ~0Ω) |
| DS18B20 VDD | J1 pin 5 → Pi Pin 1 (3.3V) | Continuity (beep / ~0Ω) |

---

## Gotchas

**1. Damaged DS18B20 pulls data line to ~0.5V**
A failed sensor with an internally shorted open-drain transistor sinks the pull-up current and holds the data line near 0.5V. The circuit checks out perfectly — continuity is good, R2 is wired correctly, VDD is present — but the sensor never appears. Isolate by disconnecting the sensor and measuring the data line; if it rises to 3.3V, replace the sensor.

**2. VDD not connected puts sensor in parasite power mode**
If J1 pin 5 (DS18B20 VDD) is not wired to 3.3V, the sensor draws power from the data line through an internal diode — this is called parasite power mode. The data line clamps to ~0.4–0.6V and the sensor is unreliable or non-functional. Always confirm VDD reads 3.2–3.3V at the sensor.

**3. R2 not at the data junction**
R2 must connect between the 3.3V rail and the specific node shared by J1 pin 3 and the GPIO4 jumper. If R2 is placed one hole off, or its bottom leg lands on a different row, the pull-up does nothing. Verify with a resistance measurement: data node to 3.3V rail should read ~4.7kΩ.

**4. All GND pins are equivalent**
Pi Pin 6 (GND) and Pin 39 (GND) are the same ground plane. If Pin 6 is occupied by another subsystem, use any other GND pin — there is no electrical difference.

**5. The overlay must be in /boot/firmware/config.txt**
On Raspberry Pi OS Bookworm, the boot config is at `/boot/firmware/config.txt` — not `/boot/config.txt` as in older releases. Adding the overlay to the wrong file has no effect.

---

## Verified Working Configuration

| Parameter | Value |
|---|---|
| Sensor | DS18B20 waterproof probe |
| Pull-up resistor | 4.7kΩ (measured 4.17kΩ — within tolerance) |
| GPIO | GPIO4 / Pi Pin 7 |
| Overlay | `dtoverlay=w1-gpio,gpiopin=4` |
| Sensor address | `28-33e70087fda7` |
| Ambient reading at verification | 24.375°C (75.9°F) |

---

*Photoplasm · HTGAA 2026 · Genspace Node · Eric Schneider · Makerspace Charlotte*

*Repository: github.com/ericview-dev/photoplasm · branch: dev*

> v1.0.0  ·  2026-06-12  ·  published

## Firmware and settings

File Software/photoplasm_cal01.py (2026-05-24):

#!/usr/bin/env python3
"""
photoplasm_cal01.py
═══════════════════════════════════════════════════════════════════
BioLight Calibration Script — Protophotoplasm platform
Part of the BioLight optogenetic bacteriography exposure unit.
HTGAA 2026 · Makerspace Charlotte BioArt Studio
═══════════════════════════════════════════════════════════════════

PURPOSE
-------
Runs a clean, repeatable 16-step sensitometric calibration cycle.
Each step projects a cumulative pie-wedge mask through the OLED
onto the substrate below, while the AS7341 spectral sensor measures
the actual delivered irradiance at 470nm per step. Results are
written to a timestamped CSV for H&D curve construction.

This is the optical equivalent of a Stouffer step wedge — wedge 1
receives 16× the base exposure, wedge 16 receives 1×. After all
16 steps the plate holds a full logarithmic dose gradient, readable
as a sensitometric curve once sfGFP fluorescence is imaged.

CYCLE SEQUENCE
--------------
  1. LEDs ON  — GPIO18 PWM at PWM_DUTY_PCT% via IRLZ44N MOSFET gate
  2. Warm-up  — allow LED output to stabilise before first measurement
  3. Wedge loop (16 steps):
       a. Render cumulative wedge frame → push to OLED via SPI
       b. Settle 300ms for OLED pixel stabilisation
       c. Read all AS7341 channels; compute F2+F3 as 470nm proxy
       d. Stamp step metadata; append row to log buffer
       e. Hold dwell remainder for biological exposure
  4. OLED OFF — send display-off command (0xAE), screen goes dark
  5. LEDs OFF — PWM duty to 0, MOSFET gate pulled low
  6. CSV write — flush all rows to timestamped file in OUTPUT_DIR
  7. Summary  — print F2+F3 ramp ratio; warn on saturation or noise floor

GAIN ADVISORY (AS7341_GAIN = "16X" default)
--------------------------------------------
  F2+F3 step 16 > 60000  →  saturating, drop to 8X
  F2+F3 step  1 <   500  →  noise floor, raise to 32X

PIN ASSIGNMENTS — NS-03 v6 Pi 5
---------------------------------
  PWM / MOSFET gate:
    Pin  1  3.3V            (logic reference)
    Pin  6  GND
    Pin 12  GPIO18 PWM0  →  IRLZ44N gate (470Ω series, 10kΩ pull-down)

  OLED SPI (SSD1309 128×64):
    Pin  9  GND
    Pin 13  GPIO27  RST
    Pin 17  3.3V    VCC
    Pin 19  GPIO10  MOSI / DIN
    Pin 22  GPIO25  DC
    Pin 23  GPIO11  SCLK
    Pin 24  GPIO8   CE0 / CS

  AS7341 spectral sensor (I2C, addr 0x39):
    Pin  1  3.3V    (shared with OLED VCC)
    Pin  3  GPIO2   SDA
    Pin  5  GPIO3   SCL
    Pin 14  GND

DEPENDENCIES
------------
  sudo apt install python3-lgpio python3-spidev python3-smbus2 python3-pil
  pip3 install adafruit-circuitpython-as7341 --break-system-packages

CLI USAGE
---------
  sudo python3 photoplasm_cal01.py [options]

  Options (all optional — defaults from CONFIG block apply if omitted):
    --dwell N       Dwell time in seconds per wedge step  (default: 5.0)
    --pwm N         LED PWM duty cycle 0–100%             (default: 100)
    --gain Nx       AS7341 gain setting                   (default: 16X)
                    choices: 0_5X 1X 2X 4X 8X 16X 32X 64X 128X 256X
    --dry-run       Skip all hardware; use synthetic sensor data.
                    Useful for validating CSV output and timing on bench.

  Examples:
    sudo python3 photoplasm_cal01.py
    sudo python3 photoplasm_cal01.py --dwell 10
    sudo python3 photoplasm_cal01.py --pwm 75 --gain 8X
    sudo python3 photoplasm_cal01.py --dwell 2 --pwm 50 --gain 32X
    python3 photoplasm_cal01.py --dry-run

  Ctrl+C aborts the cycle cleanly — LEDs and OLED are powered off
  by the finally block before the process exits.
"""

import argparse        # CLI argument parsing
import lgpio          # Pi 5 GPIO library (replaces deprecated RPi.GPIO)
import spidev         # SPI bus access for OLED
import time
import csv
import os
from datetime import datetime
from PIL import Image, ImageDraw   # wedge frame rendering

# ── AS7341 import with graceful dry-run fallback ──────────────────
# If the sensor is not wired the script still runs, using synthetic
# ramp data so the OLED wedge sequence and LED on/off can be verified
# independently. SENSOR_PRESENT flag is printed at startup.
try:
    import board
    import busio
    from adafruit_as7341 import AS7341, Gain
    _i2c = busio.I2C(board.SCL, board.SDA)
    sensor = AS7341(_i2c)
    SENSOR_PRESENT = True
    print("[AS7341] sensor found")
except Exception as e:
    sensor = None
    Gain   = None
    SENSOR_PRESENT = False
    print(f"[AS7341] not found ({e}) — running in dry-run mode")


# ══════════════════════════════════════════════════════════════════
# CLI ARGUMENT PARSING
# argparse processes sys.argv at import time so CLI flags are
# available before the CONFIG constants are referenced. Each flag
# maps directly to one CONFIG constant; the parsed value overrides
# the file default when supplied. Omitted flags fall back to the
# CONFIG defaults unchanged.
# ══════════════════════════════════════════════════════════════════
VALID_GAINS = ["0_5X","1X","2X","4X","8X","16X","32X","64X","128X","256X"]

_parser = argparse.ArgumentParser(
    prog="photoplasm_cal01",
    description="BioLight sensitometric calibration cycle — 16-step pie-wedge exposure.",
    formatter_class=argparse.RawDescriptionHelpFormatter,
    epilog=(
        "examples:\n"
        "  sudo python3 photoplasm_cal01.py\n"
        "  sudo python3 photoplasm_cal01.py --dwell 10\n"
        "  sudo python3 photoplasm_cal01.py --pwm 75 --gain 8X\n"
        "  sudo python3 photoplasm_cal01.py --dwell 2 --pwm 50 --gain 32X\n"
        "  python3 photoplasm_cal01.py --dry-run\n"
    )
)
_parser.add_argument(
    "--dwell", type=float, default=None, metavar="N",
    help="dwell time in seconds per wedge step (default: 5.0)"
)
_parser.add_argument(
    "--pwm", type=int, default=None, metavar="N",
    help="LED PWM duty cycle 0–100 percent (default: 100)"
)
_parser.add_argument(
    "--gain", type=str, default=None, choices=VALID_GAINS, metavar="Nx",
    help=f"AS7341 gain — one of: {' '.join(VALID_GAINS)} (default: 16X)"
)
_parser.add_argument(
    "--dry-run", action="store_true", dest="dry_run",
    help="skip all hardware; use synthetic sensor data (no sudo required)"
)
_args = _parser.parse_args()

# ══════════════════════════════════════════════════════════════════
# CONFIG — file defaults; CLI flags override at runtime
# ══════════════════════════════════════════════════════════════════
DWELL_SEC    = 5.0    # seconds each wedge step is held on the OLED
                      # this is your base exposure unit — wedge 1
                      # accumulates 16 × DWELL_SEC total

WARMUP_SEC   = 2.0    # settle time after LEDs energise before step 1
                      # allows thermal stabilisation of LED output

PWM_FREQ_HZ  = 1000   # MOSFET gate switching frequency in Hz
                      # 1 kHz is well above flicker threshold and
                      # below any interference with I2C or SPI buses

PWM_DUTY_PCT = 100    # LED brightness 0–100%
                      # 100 = full rated current via 6.8Ω / 2W resistor
                      # reduce here (not in hardware) for lower-dose runs

WEDGES       = 16     # number of cumulative exposure steps
                      # each step opens one additional 22.5° pie wedge
                      # 16 steps × 22.5° = full 360° circle at step 16

OUTPUT_DIR   = "/home/pi/cal_logs"          # configure this for your Pi username
                      # timestamped CSVs are written here
                      # directory is created automatically if absent

AS7341_GAIN  = "16X"  # spectral sensor gain setting
                      # mid-range starting point for ring light
                      # options: 0_5X  1X  2X  4X  8X  16X
                      #          32X  64X  128X  256X
                      # see GAIN ADVISORY in module docstring above

# ── Apply CLI overrides (flags take priority over file defaults) ──
if _args.dwell    is not None: DWELL_SEC    = _args.dwell
if _args.pwm      is not None: PWM_DUTY_PCT = _args.pwm
if _args.gain     is not None: AS7341_GAIN  = _args.gain
if _args.dry_run:               SENSOR_PRESENT = False   # force dry-run mode
# ══════════════════════════════════════════════════════════════════


# ── GPIO / SPI pin constants (from NS-03 v6 table — do not edit) ──
GPIO_PWM = 18    # hardware PWM0 → IRLZ44N gate
GPIO_RST = 27    # OLED hard reset line
GPIO_DC  = 25    # OLED data / command select

# ── OLED display dimensions ────────────────────────────────────────
OLED_W = 128     # pixels wide
OLED_H = 64      # pixels tall

# ── SSD1309 power control command bytes ───────────────────────────
CMD_DISPLAY_OFF = 0xAE   # blank screen, preserve RAM
CMD_DISPLAY_ON  = 0xAF   # restore display from RAM


# ══════════════════════════════════════════════════════════════════
# OLED DRIVER
# Minimal SPI driver for the SSD1309 128×64 OLED.
# Uses lgpio for GPIO control (Pi 5 / Bookworm compatible).
# ══════════════════════════════════════════════════════════════════
class OLED:
    def __init__(self, h, spi):
        """
        h   — lgpio chip handle (from lgpio.gpiochip_open)
        spi — spidev SpiDev instance (bus 0, device 0)
        """
        self.h   = h
        self.spi = spi

    def _cmd(self, c):
        """Send a single command byte. DC low = command mode."""
        lgpio.gpio_write(self.h, GPIO_DC, 0)
        self.spi.xfer2([c])

    def _data(self, buf):
        """
        Send pixel data buffer. DC high = data mode.
        Chunked at 4096 bytes to stay within spidev transfer limits.
        """
        lgpio.gpio_write(self.h, GPIO_DC, 1)
        for i in range(0, len(buf), 4096):
            self.spi.xfer2(buf[i:i + 4096])

    def reset(self):
        """
        Hardware reset pulse: RST high → low → high with 10ms holds.
        Required on power-up to initialise the SSD1309 controller.
        """
        lgpio.gpio_write(self.h, GPIO_RST, 1); time.sleep(0.01)
        lgpio.gpio_write(self.h, GPIO_RST, 0); time.sleep(0.01)
        lgpio.gpio_write(self.h, GPIO_RST, 1); time.sleep(0.01)

    def init(self):
        """
        Full SSD1309 initialisation sequence.
        Sets clock, multiplex ratio, addressing mode, contrast, and
        charge pump before turning the display on. Values are fixed
        for the Waveshare 128×64 SPI OLED module.
        """
        self.reset()
        for c in [
            0xAE,       # display off during init
            0xD5, 0x80, # oscillator frequency / clock divide ratio
            0xA8, 0x3F, # multiplex ratio = 64 rows
            0xD3, 0x00, # display offset = 0 (no vertical shift)
            0x40,       # display start line = 0
            0x8D, 0x14, # charge pump enabled (required — no external Vcc)
            0x20, 0x00, # horizontal addressing mode
                        # auto-increments column then page — suits row-by-row push
            0xA1,       # segment re-map: col 127 → SEG0 (mirror horizontally)
            0xC8,       # COM scan direction: remapped (flip vertically)
            0xDA, 0x12, # COM pins hardware config: alt, no remap
            0x81, 0xCF, # contrast = 0xCF (bright; reduce if too intense)
            0xD9, 0xF1, # pre-charge period: phase1=1, phase2=15
            0xDB, 0x40, # VCOMH deselect level = 0.77 × Vcc
            0xA4,       # display follows RAM (not all-on)
            0xA6,       # normal polarity (1 = lit pixel)
            0xAF,       # display on
        ]:
            self._cmd(c)

    def show(self, img: Image.Image):
        """
        Push a PIL image to the OLED framebuffer.

        The SSD1309 stores pixels as vertical 8-pixel pages across
        128 columns. Each byte in the buffer represents 8 vertically
        stacked pixels in one column of one page (bit 0 = top row).

        Process:
          - Convert image to 1-bit (black/white)
          - Walk 8 pages × 128 columns
          - Pack 8 vertical pixels per column into one byte
          - Set column (0x21) and page (0x22) address windows
          - Send packed buffer as data
        """
        bw  = img.convert("1")
        buf = []
        for page in range(8):             # 8 pages × 8 rows = 64 rows total
            for col in range(OLED_W):     # 128 columns
                byte = 0
                for bit in range(8):
                    row = page * 8 + bit  # absolute pixel row
                    px  = bw.getpixel((col, row))
                    if px:
                        byte |= (1 << bit)   # set bit; bit 0 = topmost row in page
                buf.append(byte)
        self._cmd(0x21); self._cmd(0); self._cmd(127)   # column address 0–127
        self._cmd(0x22); self._cmd(0); self._cmd(7)     # page address 0–7
        self._data(buf)

    def off(self):
        """Blank the display. Pixel RAM is preserved — on() restores it."""
        self._cmd(CMD_DISPLAY_OFF)

    def on(self):
        """Restore display from RAM after off()."""
        self._cmd(CMD_DISPLAY_ON)


# ══════════════════════════════════════════════════════════════════
# WEDGE FRAME GENERATOR
# Produces the cumulative pie-wedge exposure masks displayed on the
# OLED at each step of the calibration cycle.
# ══════════════════════════════════════════════════════════════════
def make_wedge_frame(step: int, total: int = 16) -> Image.Image:
    """
    Generate a 128×64 1-bit PIL image for calibration step N.

    The image is WHITE (opaque mask) except for N cumulative dark pie
    wedge cutouts. Light passes through the dark sectors only — the
    white areas block the LED output entirely.

    Biological meaning:
      Step  1 → 1 dark wedge cut   → that zone gets 1 exposure unit
      Step  2 → 2 dark wedges cut  → zone 1 gets 2 units, zone 2 gets 1
      Step 16 → all wedges cut     → zone 1 has 16 units, zone 16 has 1
    After all 16 steps the plate holds a full logarithmic dose gradient.

    Geometry:
      Circle inscribed in OLED height (radius = 31px, centred at 64,32).
      Area outside the circle remains white (fully masked) at all steps.

    Args:
      step  — current step number (1–total), controls how many wedges open
      total — total number of wedges (default 16)

    Returns:
      PIL Image, mode "1", size 128×64
    """
    # MASK LOGIC (corrected):
    # OLED starts fully WHITE — the entire screen blocks light (opaque mask).
    # Each step cuts a DARK wedge out of the mask — dark = transparent = light passes.
    # Result: light only reaches the substrate through the dark wedge cutouts.
    # Step 1 = one dark wedge open (1 exposure unit to that zone).
    # Step 16 = all dark wedges open (full circle exposed, zone 1 has 16 units).
    # This is the correct Stouffer step-wedge geometry for cumulative exposure.
    img    = Image.new("1", (OLED_W, OLED_H), 1)   # start fully white (opaque mask)
    draw   = ImageDraw.Draw(img)

    cx, cy        = OLED_W // 2, OLED_H // 2        # centre = (64, 32)
    r             = OLED_H // 2 - 1                 # radius = 31px (1px margin)
    deg_per_wedge = 360.0 / total                   # 22.5° per wedge at 16 steps
    start_angle   = -90.0                           # 0° at 12 o'clock (PIL uses 3 o'clock = 0°)

    for w in range(step):
        a0 = start_angle + w * deg_per_wedge        # wedge start angle
        a1 = a0 + deg_per_wedge                     # wedge end angle
        draw.pieslice(
            [cx - r, cy - r, cx + r, cy + r],       # bounding box of circle
            start=a0, end=a1, fill=0                 # fill=0 = dark = light passes through
        )
    return img


# ══════════════════════════════════════════════════════════════════
# AS7341 SPECTRAL MEASUREMENT
# Reads all 10 channels plus a computed 470nm proxy (F2+F3 sum).
# ══════════════════════════════════════════════════════════════════
def read_as7341() -> dict:
    """
    Read all AS7341 spectral channels and return as a flat dict.

    470nm proxy — F2 (445nm) + F3 (480nm):
      The AS7341 has no channel centred on 470nm. The 470nm EL222
      absorption peak falls in the gap between F2 and F3. Summing
      both channels gives a stable dose proxy across runs; use the
      same gain setting for all runs in a series so values are
      directly comparable.

    Gain is applied fresh each call from AS7341_GAIN config constant.
    This is safe because gain takes effect immediately and the sensor
    has no persistent state between calls.

    Dry-run mode (SENSOR_PRESENT = False):
      Returns a static synthetic reading so the rest of the cycle
      (OLED wedges, LED control, CSV write) can be validated without
      the sensor connected.

    Returns:
      dict with keys: f1_415nm … f8_680nm, clear, nir, f2_f3_sum
    """
    if not SENSOR_PRESENT:
        # Synthetic values — proportional to a mid-range real reading.
        # Enough to confirm CSV structure and summary math without sensor.
        return {
            "f1_415nm":  0,  "f2_445nm": 100, "f3_480nm": 120,
            "f4_515nm": 50,  "f5_555nm":  30, "f6_590nm":  20,
            "f7_630nm": 15,  "f8_680nm":  10, "clear":    300,
            "nir":       5,  "f2_f3_sum": 220
        }

    # Apply gain from config — mid-range 16X default for ring light
    sensor.gain = getattr(Gain, f"GAIN_{AS7341_GAIN}")

    ch = {
        "f1_415nm" : sensor.channel_415nm,   # violet
        "f2_445nm" : sensor.channel_445nm,   # deep blue  ← EL222 lower bound
        "f3_480nm" : sensor.channel_480nm,   # blue       ← EL222 upper bound
        "f4_515nm" : sensor.channel_515nm,   # cyan
        "f5_555nm" : sensor.channel_555nm,   # green
        "f6_590nm" : sensor.channel_590nm,   # yellow-green
        "f7_630nm" : sensor.channel_630nm,   # orange-red
        "f8_680nm" : sensor.channel_680nm,   # red
        "clear"    : sensor.channel_clear,   # broadband (no filter)
        "nir"      : sensor.channel_nir,     # near-infrared
    }
    ch["f2_f3_sum"] = ch["f2_445nm"] + ch["f3_480nm"]   # 470nm proxy
    return ch


# ══════════════════════════════════════════════════════════════════
# LED PWM HELPERS
# Thin wrappers around lgpio hardware PWM on GPIO18.
# The IRLZ44N MOSFET switches the 12V LED rail; the Pi never
# carries LED current directly.
# ══════════════════════════════════════════════════════════════════
def leds_on(h, duty_pct: int = 100):
    """
    Start hardware PWM on GPIO18 at duty_pct% (0–100).
    Clamped to valid range. Drives IRLZ44N gate, switching 12V LED rail.
    """
    duty = max(0, min(100, duty_pct))
    lgpio.tx_pwm(h, GPIO_PWM, PWM_FREQ_HZ, duty)
    print(f"[LED] ON — {duty}% duty cycle")


def leds_off(h):
    """
    Turn LEDs off — two-step for reliability:
      1. tx_pwm duty to 0 stops the PWM signal
      2. gpio_write pulls the gate pin explicitly low
    The explicit gpio_write is necessary because lgpio's tx_pwm
    at 0% duty can leave the pin in an indeterminate state on some
    Pi 5 / Bookworm combinations, keeping the MOSFET partially on.
    Explicit low guarantees the gate is pulled to GND.
    """
    lgpio.tx_pwm(h, GPIO_PWM, PWM_FREQ_HZ, 0)     # stop PWM
    lgpio.gpio_write(h, GPIO_PWM, 0)               # pull gate explicitly low
    print("[LED] OFF")
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

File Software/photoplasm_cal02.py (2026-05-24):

#!/usr/bin/env python3
"""
photoplasm_cal02.py
═══════════════════════════════════════════════════════════════════
BioLight Irradiance Calibration — Protophotoplasm platform
Part of the BioLight optogenetic bacteriography exposure unit.
HTGAA 2026 · Makerspace Charlotte BioArt Studio
Eric Schneider + Karen Ingram
═══════════════════════════════════════════════════════════════════

PURPOSE
-------
Measures actual delivered irradiance at agar base height across
three optical states. Establishes the calibrated baseline for all
subsequent biological exposure runs.

This script contains NO step wedge logic. The step wedge is a
biological exposure tool (protophotoplasm.py) and runs only after
calibration is complete and gain/PWM values are confirmed.

CALIBRATION STATES
------------------
  State 1 — LED ON, no OLED (maximum possible irradiance)
    Sensor reads full unobstructed LED field at agar plane.
    This is the optical ceiling — nothing can exceed this value.

  State 2 — LED ON, OLED fully WHITE (maximum block)
    OLED glass + pixel layer at full white attenuates the beam.
    Measures the transmission loss of the OLED substrate itself.
    White pixels on SSD1309 = pixels ON = OLED emitting = blocking
    the 470nm LED light passing through from below.

  State 3 — LED ON, OLED fully OFF (display dark, glass only)
    Display command 0xAE blanks all pixels but glass remains.
    Measures glass-only transmission loss with no pixel attenuation.
    This is the working irradiance for biological exposure runs.

DERIVED METRICS
---------------
  oled_transmission   = state2_f2f3 / state1_f2f3
    How much light passes through the full OLED (white pixels + glass)
    as a fraction of unobstructed LED output. Typically 60–80%.

  glass_transmission  = state3_f2f3 / state1_f2f3
    How much light passes through the OLED glass alone (pixels off).
    Typically 85–95%.

  pixel_attenuation   = state3_f2f3 / state2_f2f3
    How much additional blocking the lit pixels add over glass alone.
    Useful for understanding OLED contrast ratio in the optical path.

  irradiance_uwcm2    = f2_f3_sum × k_factor
    Estimated irradiance in µW/cm² at the sensor plane.
    k_factor must be established by comparison with a calibrated
    reference meter. Default k=1.0 until measured.

SENSOR PLACEMENT
----------------
  AS7341 at agar base height, in transmission geometry directly
  under the OLED projection zone. This measures the actual photon
  flux delivered to the biological substrate plane — the ground
  truth for EL222 activation dose.

  Sensor must remain at this fixed position for all calibration
  and exposure runs so readings are directly comparable.

CYCLE SEQUENCE
--------------
  1. Hardware init — GPIO, SPI, I2C
  2. LEDs ON at PWM_DUTY_PCT%
  3. Warm-up settle (WARMUP_SEC)
  4. State 1: OLED absent/off → read AS7341 → log
  5. State 2: OLED white (full block) → settle → read AS7341 → log
  6. State 3: OLED display off (glass only) → settle → read AS7341 → log
  7. LEDs OFF
  8. OLED OFF
  9. Compute and print transmission ratios
  10. Write CSV

GAIN ADVISORY
-------------
  F2+F3 > 60000  →  saturating, drop gain
  F2+F3 <   500  →  noise floor, raise gain
  Starting point: 256X for current ring light at agar base height.
  Adjust --gain flag until state 1 reads 1000–50000 counts.

PIN ASSIGNMENTS — NS-03 v6 Pi 5
---------------------------------
  PWM / MOSFET gate:
    Pin  1  3.3V            (logic reference)
    Pin  6  GND
    Pin 12  GPIO18 PWM0  →  IRLZ44N gate (470Ω series, 10kΩ pull-down)

  OLED SPI (SSD1309 128×64):
    Pin  9  GND
    Pin 13  GPIO27  RST
    Pin 17  3.3V    VCC
    Pin 19  GPIO10  MOSI / DIN
    Pin 22  GPIO25  DC
    Pin 23  GPIO11  SCLK
    Pin 24  GPIO8   CE0 / CS

  AS7341 spectral sensor (I2C, addr 0x39):
    Pin  1  3.3V    (shared with OLED VCC)
    Pin  3  GPIO2   SDA
    Pin  5  GPIO3   SCL
    Pin 14  GND

DEPENDENCIES
------------
  sudo apt install python3-lgpio python3-spidev python3-smbus2 python3-pil
  sudo pip3 install adafruit-circuitpython-as7341 --break-system-packages

CLI USAGE
---------
  sudo python3 photoplasm_cal02.py [options]

  Options:
    --pwm N       LED PWM duty cycle 0–100%   (default: 100)
    --gain Nx     AS7341 gain setting          (default: 256X)
                  choices: 0_5X 1X 2X 4X 8X 16X 32X 64X 128X 256X
    --settle N    Settle time in seconds between states (default: 2.0)
    --k N         k_factor for µW/cm² estimate (default: 1.0)
    --dry-run     No hardware — synthetic data for bench validation

  Examples:
    sudo python3 photoplasm_cal02.py
    sudo python3 photoplasm_cal02.py --gain 128X
    sudo python3 photoplasm_cal02.py --pwm 75 --gain 256X
    python3 photoplasm_cal02.py --dry-run

  Ctrl+C exits cleanly — LEDs and OLED powered off by finally block.
"""

import argparse
import lgpio
import spidev
import time
import csv
import os
from datetime import datetime
from PIL import Image, ImageDraw


# ── AS7341 import with graceful dry-run fallback ──────────────────
try:
    import board
    import busio
    from adafruit_as7341 import AS7341, Gain
    _i2c   = busio.I2C(board.SCL, board.SDA)
    sensor = AS7341(_i2c)
    SENSOR_PRESENT = True
    print("[AS7341] sensor found")
except Exception as e:
    sensor = None
    Gain   = None
    SENSOR_PRESENT = False
    print(f"[AS7341] not found ({e}) — dry-run mode")


# ══════════════════════════════════════════════════════════════════
# CLI ARGUMENT PARSING
# ══════════════════════════════════════════════════════════════════
VALID_GAINS = ["0_5X","1X","2X","4X","8X","16X","32X","64X","128X","256X"]

_parser = argparse.ArgumentParser(
    prog="photoplasm_cal02",
    description="BioLight irradiance calibration — three-state optical baseline.",
    formatter_class=argparse.RawDescriptionHelpFormatter,
    epilog=(
        "examples:\n"
        "  sudo python3 photoplasm_cal02.py\n"
        "  sudo python3 photoplasm_cal02.py --gain 128X\n"
        "  sudo python3 photoplasm_cal02.py --pwm 75 --gain 256X\n"
        "  python3 photoplasm_cal02.py --dry-run\n"
    )
)
_parser.add_argument("--pwm",     type=int,   default=None, metavar="N",
    help="LED PWM duty cycle 0–100 (default: 100)")
_parser.add_argument("--gain",    type=str,   default=None, choices=VALID_GAINS, metavar="Nx",
    help=f"AS7341 gain — one of: {' '.join(VALID_GAINS)} (default: 256X)")
_parser.add_argument("--settle",  type=float, default=None, metavar="N",
    help="settle time in seconds between states (default: 2.0)")
_parser.add_argument("--k",       type=float, default=None, metavar="N",
    help="k_factor for µW/cm² estimate (default: 1.0)")
_parser.add_argument("--dry-run", action="store_true", dest="dry_run",
    help="skip all hardware, use synthetic data")
_args = _parser.parse_args()
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

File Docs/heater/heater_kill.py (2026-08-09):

#!/usr/bin/env python3
"""
heater_kill.py - EMERGENCY: force the heater gate LOW immediately.

Independent of any running calibration script. Claims GPIO13 and drives it LOW,
turning the MOSFET (and PTC) off. Run this any time the gate must be forced off.

    python3 heater_kill.py

Note: the surest physical stop is still to cut the 12 V supply - the heater
cannot heat with no 12 V regardless of gate state. This handles the gate side.
"""
import lgpio

GATE = 13
CHIP = 0   # match your working gpiochip (some Pi 5 setups use 4)

h = lgpio.gpiochip_open(CHIP)
try:
    lgpio.gpio_claim_output(h, GATE, 0)   # claim as output, drive LOW
    lgpio.gpio_write(h, GATE, 0)
    print("GPIO13 forced LOW - heater gate OFF.")
finally:
    lgpio.gpio_free(h, GATE)
    lgpio.gpiochip_close(h)

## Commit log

2026-04-26 Initial commit — Photoplasm alpha scripts v0.1
    Hardware-verified scripts from Pi 5 (eyepi) development session:
    - as7341_test.py: AS7341 10-channel spectral sensor read
    - gpio_test.py: GPIO18 LED on/off test
    - hello.py: VS Code remote SSH verification script
    - leds_off.py: LED ring off command
    - leds_on.py: LED ring on command
    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
2026-04-26 Updated README — added Photoplasm project description
2026-04-26 fix: rewrite AS7341 init to use smbus2 — fixes SSH remote execution hang
    [as7341_test.py]
2026-04-26 fix: add stdout line buffering for SSH output visibility
    [as7341_test.py]
2026-04-27 test: add AS7341 Adafruit library version with BLINKA_FORCEBOARD fix for SSH
    [as7341_adafruit_test.py]
2026-04-27 fix: use Gain enum for AS7341 gain setting
    [as7341_adafruit_test.py]
2026-04-27 test: add AS7341 gain sweep script for 470nm LED ring optimization
2026-04-28 feat: add photoplasm_cal01.py — 16-step sensitometric calibration cycle
    - LEDs on/off via GPIO18 IRLZ44N PWM
    - Cumulative pie-wedge OLED sequence (SSD1309 SPI)
    - AS7341 spectral measurement per step, GAIN_16X default
    - F2+F3 sum as 470nm proxy, saturation/noise-floor advisories
    - CLI flags: --dwell --pwm --gain --dry-run
    - Timestamped CSV output to cal_logs/
    - Updated .gitignore with cal_logs/ and .DS_Store
    [photoplasm_cal01.py]
2026-04-28 fix: invert OLED wedge mask + reliable LED off
    - make_wedge_frame: white background with dark cutouts (correct mask geometry)
    - leds_off: add explicit gpio_write low after tx_pwm to fix LED staying on
    [photoplasm_cal01.py]
2026-04-28 feat: add photoplasm_cal02.py — three-state irradiance calibration
    - replaces step wedge with clean no_oled/oled_white/oled_off states
    - computes OLED transmission, glass transmission, pixel attenuation
    - wide CSV format — one row per run
    - k_factor for µW/cm² conversion once reference meter available
    [photoplasm_cal02.py]
2026-04-28 fix: 5s dwell per Bayer step, read at 4.5s
    [photoplasm_densitometer.py]
2026-04-28 fix: derive MEASURE_DELAY from SETTLE_SEC, clean up argparse
    [photoplasm_densitometer.py]
2026-04-28 fix: add oled.on() before density frames after step 0 display-off
    [photoplasm_densitometer.py]
2026-05-24 docs: add /docs directory with 10-chapter quick start guide and appendices
    Covers SSH setup, GitHub workflow, hardware chapters (LED ring, OLED mask,
    heater, camera), system integration, Flask GUI spec, calibration protocol,
    feature specification, and pinout reference for NS-03 v8.
2026-05-24 fix: replace hardcoded username in OUTPUT_DIR with generic /home/pi path
    [photoplasm_cal01.py, photoplasm_cal02.py, photoplasm_densitometer.py]
2026-07-02 Add heater calibration scripts + validation guides
2026-07-02 Calibration: add target, hold, cooldown phases
2026-07-02 Fix: no plateau abort in target mode; cooldown to baseline
    [heater_calibration.py]
2026-07-03 Add heater_kill.py + hold runtime guard; fix plateau/cooldown
    [heater_calibration.py, heater_kill.py]
2026-08-02 docs: add Appendix D — DS18B20 1-Wire sensor wiring and troubleshooting guide
2026-08-09 feat: add 3D print files — lower stage sensor mount (STL)
    [lower_stage_sensor.stl]
2026-08-16 Add files via upload
    this is the plate holder. must be PETG
    [Plate_Holder.stl]
2026-08-24 Add 3D/ — printable mechanical parts for the exposure unit
    17 files, ~1.6 MB. Binary STL exported from Fusion 360 (source CAD is not
    tracked here), plus one STEP and one 3MF where those formats were the export.
    3d_readme.md is the authority: parts 01-12 indexed by ID, file, and the feature
    each serves — plate holder, lower stage sensor mount, LCD carrier, cone and 1 in
    cone spacer, heater spacer, Pi 5 mount, GPIO breakout mount, heater mount,
    heater circuit holder, temp cutoff ring, and the switch box.
    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
    [Cone.stl, Cone_Spacer_1in.stl, HeaterSpacer.stl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]
2026-08-24 3D: drop the superseded part 11 halves, update the readme
    Removes tempcut_ring.stl, tempcut.stl and tempcut_ring.step. All three were
    reference-only, never printables — the merged tempcut_combined_holder.stl has
    been the single printable for part 11 since 2026-08-21. Their exports were not
    even co-located (the ring sat at z -1131, the pocket at z 0), so they were a
    standing trap for anyone reading those coordinates as stack positions.
    readme updated where it still described them as kept-for-reference: the part 11
    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
    [tempcut.stl, tempcut_ring.step, tempcut_ring.stl]
2026-08-24 3D: add part 13 light spacer lower ring; make PETG the device-wide rule
    Part 13 — lightspacer_lower_ring.stl. Retaining ring that stops the light
    spacer slipping down into the enlarger body. Friction fit and adjustable: its
    height on the spacer sets how deep the spacer sits.
    Measured from the mesh: 159.94 mm OD, 149.78 mm ID, 5.08 mm wall (exactly
    0.200 in), 27.40 mm tall. Two Z levels and two radii, so a plain extruded
    annulus — no register lip, no taper, no fastener features. Everything it does,
    it does by interference. The imperial wall suggests it was dimensioned against
    the enlarger's own hardware rather than the metric printed stack.
    D-13 flags that the two numbers deciding wheth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
    [lightspacer_lower_ring.stl]
2026-08-24 3D: add part 14 Cree light ring
    Cree_lightring.stl — carrier for the Cree XP-E2 470 nm array, replacing the
    Bogen enlarger's original lamphouse. Largest part on the device at
    174.62 x 174.57 x 42.86 mm.
    Measured from the mesh (6 concentric Z levels): an outer skirt of 174.62 mm OD
    and 149.22 mm bore with a 12.70 mm wall — exactly 0.500 in — running the full
    32.20 mm height; a 3.20 mm web plate set high within it; a Ø37.77 mm central hub
    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
    [Cree_lightring.stl]
2026-08-24 3D: add part 15 light spacer; resolves the parts 13/14 mating question
    lightspacer_large.stl — the column that raises the Cree light ring to optical
    height, setting the throw for projection convergence. 149.74 x 149.76 x
    92.07 mm, three Z levels.
    This is the Ø~149 tube D-14 inferred but could not confirm. It exists, and the
    two "suspiciously close" bores turn out to be two different stations on one
    part:
    joint bore spacer OD interference
    14 light ring -> top Ø149.22 Ø149.26 +0.04 mm
    13 lower ring -> bottom Ø149.78 Ø149.82 +0.04 mm
    Same interference at both, doing different jobs. The top 15.88 mm tapers
    Ø149.82 -> Ø1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
    [lightspacer_large.stl]
2026-08-24 3D: the light spacer height is tunable by design, not an undocumented value
    D-15 had recorded the 92.07 mm as "not derived — the throw calculation is not
    written down anywhere," treating a deliberate design state as an omission. It
    is not. The height is intentionally provisional: optimal optical height is being
    determined empirically by moving the emitter until projection convergence at the
    substrate plane is best, and the number gets recorded after that, not before.
    Reframed accordingly. Part 13's 48.79 mm of travel is not slop to be engineered
    out — it is the tuning range, and it stays open until the optimum is found. Part
    13 is currently a tuning fixture, not final hardware.
    Lock-in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
2026-08-24 3D: part 13 rev 2 — drafted bore, press fit (rev 1 slipped)
    lightspacer_lower_ring_draft.stl. Rev 1's straight Ø149.78 bore did not hold in
    practice, which is what D-15 warned about: against the spacer's Ø149.82 that was
    +0.04 mm diametral, 0.02 mm on radius, finer than FDM repeatability. The fit
    landed wherever the print landed, and it landed loose.
    Rev 2 tapers the bore at a 1.00 deg half-angle — Ø149.74 at the top narrowing to
    Ø148.79 at the bottom. OD unchanged at Ø159.97 and the envelope is identical, so
    it drops into the same place.
    The taper narrows DOWNWARD, which is the load direction: the spacer's weight
    pushes it down into the narrowing bore, so the joint self-tightens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
    [lightspacer_lower_ring_draft.stl]
2026-08-25 drop stray 1-byte '3d' file — collides with 3D/ on case-insensitive filesystems
    Created via the GitHub web UI ('Create 3d'). It is a 1-byte empty blob, and on
    macOS/APFS the path '3d' is the same path as the '3D/' parts directory, so
    checking it out is impossible without destroying 15 tracked STLs. git correctly
    refused the merge rather than clobber them.
2026-08-25 Consolidate lower_stage_sensor.stl to 3D/ — remove the duplicate copies
    Keeps 3D/lower_stage_sensor.stl as the single canonical copy and removes the
    two others:
    - lower_stage_sensor.stl at the repo root, added by a web upload in the commits
    just merged. Byte-for-byte identical to the 3D/ copy (both
    d23dc38cc6eecded2754b52ac84193ed9e4425de), so nothing unique is lost.
    - docs/3D/WavelengthSensor/lower_stage_sensor.stl, the pre-consolidation
    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
    [lower_stage_sensor.stl]
2026-08-25 Remove superseded docs/3D/Plate_Holder.stl — 3D/ is the single source
    Deletes the Aug-16 web upload of part 01, leaving 3D/Plate_Holder.stl as the
    only copy. Timestamps establish which is which:
    2026-08-16 13:03:14 local file created
    2026-08-16 13:06:34 uploaded to docs/3D/ <- snapshot frozen here
    2026-08-17 12:21:38 local file re-exported <- diverges
    2026-08-24 Aug-17 revision committed into 3D/
    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
    [Plate_Holder.stl]
2026-08-25 3D: correct the part 01 air-passage revision note — it ADDED material
    D-01 said the 2026-08-17 revision 'removed geometry rather than adding it.'
    That is backwards, and the two meshes prove it. Both are closed and manifold,
    so the volumes are reliable:
    Aug 16 pre-revision 33.27 cm3 7,836 tris
    Aug 17 current 64.35 cm3 7,428 tris
    envelope 113.05 x 113.00 x 31.75 mm, unchanged
    ~93% more material in the same envelope, with FEWER triangles.
    The rationale is now recorded, because the numbers invite exactly the wrong
    conclusion. The first build needed supports, and they printed inside the airflow
    grid — the one place they must not be. They clogged the passage the grid exis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
2026-08-26 3D: record the heat-set insert + standoff standard, M3 and M2
    Consolidates the insert/standoff spec that was scattered across D-01, D-03 and
    D-09 into one device-wide section, and adds the M2 column.
    Key learning, 2026-08-26: perfboard mounting holes are M2-sized and an M3 bolt
    does not fit. The M3 standard is correct for printed-part-to-printed-part and
    module mounts (parts 09, 10), but any standoff carrying a perfboard must be M2.
    M2 derived by the same bore rule as M3 — sit just above d1 so the knurl clears
    and enters, well under OD so it still bites: d1 ~2.8 -> bore Ø3.0, post Ø7.0 at
    a 2 mm wall. Bolt is M2 x 5 for a 1.5 mm board, giving full insert engagement at
    1.5xD, better tha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
2026-08-27 3D: add part 16 light circuit hat, and part 13's Bambu project
    light_circuit_hat.stl -- the closed cap over the Cree light ring, carrying the
    NS-04 perfboard that replaces the breadboarded blue-rail CTRL circuit. Drops into
    part 14's Ø149.22 bore as a spigot at Ø149.23 and seats on its web plate at
    Z 13.00, clearing the 10.66 mm protrusion. 149.23 x 149.18 x 42.10 mm.
    The central wire porthole now measures Ø12.00 mm as intended -- an earlier export
    had it at Ø7.62 (0.300 in), which would have been tight for four wires plus the
    planned sleeve.
    Recorded as open: the four Ø4.0 standoff bores break through the top face,
    verified from the mesh (they span the full 10 mm and top-face materia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
    [light_circuit_hat.stl, lightspacer_lower_ring.3mf]
2026-08-31 LICENSE: format the multi-license rewrite; fix swapped /3D and /docs
    Formats the three-part licensing statement from main into a readable structure,
    and corrects a substantive error in it.
    ⚠ SUBSTANTIVE FIX -- the section labels were swapped. The summary paragraph says
    documentation is CC BY-SA 4.0 and hardware designs are CERN-OHL-S v2, but the
    body assigned /3D to CC BY-SA and /DOCS to CERN-OHL-S -- the reverse. The
    CERN-OHL-S paragraph's own wording gives it away: it reads "This hardware design
    is licensed under..." while sitting under a /DOCS heading. 3D/ holds STL/STEP/3MF
    hardware designs; docs/ holds written chapters. Corrected so the body matches
    both the summary and the license t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
2026-08-31 LICENSE: format the multi-license statement; fix swapped /3D and /docs
    Formats the three-part licensing statement into a readable structure and
    corrects a substantive error in it.
    both the summary and the license texts' own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
2026-08-31 Reorganise into 3D / Docs / Software; align LICENSE and README
    Moves the repository to a three-way structure matching the three licensing
    regimes, so scope is legible from the directory tree alone.
    3D/ hardware designs CERN-OHL-S v2
    Docs/ documentation CC BY-SA 4.0
    Software/ source code MIT
    Done with git mv, so history follows all 36 files and no content changes. The
    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
2026-08-31 gitignore: exclude 3D/inventory_audit.md
    Personal working notes rather than a repo artifact. The file itself says so --
    "Scratch file. Not the authority -- 3d_readme.md is. Delete this once the pass is
    done." It records the 2026-08-18 audit that confirmed each mesh in 3D/ is the
    current build, derived from bounding boxes and the Fusion coordinates baked into
    the STLs.
    It has been deliberately left untracked through several commits; ignoring it
    stops it appearing as untracked noise in every git status and removes the chance
    of it being swept in by a git add -A.
    The file stays on disk untouched.
2026-10-04 Build: the printed build guide, and the ignore rule that was hiding it
    /Build carries the chapter 02 build guide as a PDF -- 78 pages, every
    instruction numbered 02.0.1 through 02.9.20, opening on a table of contents that
    nests all 115 steps under their modules. It is generated from the same chapter
    descriptor the online activities are built from, so the paper and the screen
    cannot describe different procedures.
    The folder was untracked and not obviously so. `build/` in .gitignore is there
    for Python packaging output, and git matches ignores case-insensitively on this
    filesystem -- so /Build was being swallowed by a rule meant for /build. Exempted
    by name rather than by loosening the packag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
2026-10-04 Build -> Guide
    Renamed, and the name matters: `build/` in the packaging block of .gitignore
    also matches /Build on a case-insensitive filesystem, which is how the printed
    guide was ignored with nothing in `git status` to say so. /Guide collides with
    nothing, so the exemption added for /Build is gone and a note stands in its
    place.
2026-10-04 LICENSE: scope the docs licence to /Guide, and let MIT follow the code
    The rewrite confined MIT to /Software, which silently relicensed three files --
    Docs/heater/heater_kill.py and its two siblings -- from MIT to share-alike. A
    kill script is source code wherever it is filed, so the nature-over-placement
    rule is back and stated in both the clause and the summary.
    /DOCS named a directory that does not exist; it is /Docs. And /Guide, which
    holds the printed build guides, was in no scope at all -- documentation by
    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

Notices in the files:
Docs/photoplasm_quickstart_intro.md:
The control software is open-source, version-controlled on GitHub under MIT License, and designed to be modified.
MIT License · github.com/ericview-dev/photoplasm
